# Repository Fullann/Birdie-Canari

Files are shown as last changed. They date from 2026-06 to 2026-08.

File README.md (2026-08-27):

# 🐦 Birdie DIY — Moniteur de qualité d'air open source

> **Reproduction DIY du projet [Birdie® Fresh Air Monitor™](https://birdie.design/fr)** — un indicateur visuel de qualité d'air basé sur le CO2, inspiré du canari des mineurs. Lorsque l'air est bon, l'oiseau se dresse. Lorsque le CO2 dépasse un seuil, il s'abaisse pour vous signaler d'ouvrir les fenêtres.

***

## 📖 À propos du projet

[Birdie®](https://birdie.design/fr) est un produit commercial primé qui utilise un capteur CO2 suisse pour indiquer la qualité de l'air intérieur via une aiguille mobile en forme d'oiseau. Ce dépôt est une **implémentation DIY open source** de ce concept.

La logique de déclenchement est fidèle à l'originale :
- L'oiseau **descend** après **10 minutes consécutives** au-dessus de **1000 ppm** (pas instantanément, pour éviter les faux positifs)
- L'oiseau **remonte** dès que le CO2 repasse sous **950 ppm** (hystérésis de 50 ppm pour éviter les oscillations)

***

## ✨ Fonctionnement

```
CO2 < 950 ppm   → oiseau en haut  (air excellent)
CO2 > 1000 ppm  → oiseau en bas   (aérez !)
  (après 10 min consécutives au-dessus du seuil)
```

Inspiré du canari des mineurs : autrefois, les mineurs emmenaient un canari dans les mines pour détecter les gaz toxiques. Birdie® transpose ce principe à la maison moderne.

***

## 🧰 Matériel nécessaire

| Composant | Référence | Rôle |
|---|---|---|
| Microcontrôleur | XIAO ESP32C6 (Seeed Studio) | Cerveau du projet, Wi-Fi, ESPHome |
| Capteur CO2 | Sensirion SCD41 | CO2, température, humidité (I2C) |
| Servo | SG90 | Indicateur visuel (aiguille oiseau) |
| Chargeur batterie | TP4056 avec protection (DW01A) | Charge LiPo via USB-C/micro-USB |
| Boost converter | MT3608 | Monte la tension 3.7 V → 5 V pour le servo |
| Batterie | LiPo 1S 3.7 V – 3800 mAh | Alimentation principale |
| R1 | 100 kΩ | Pont diviseur batterie (bras haut) |
| R2 | 100 kΩ | Pont diviseur batterie (bras bas) |
| Câbles Dupont | — | Connexions |

***

## 🔌 Schéma d'alimentation

La chaîne d'alimentation fonctionne ainsi :

```mermaid
flowchart TD
    %% No HTML tags in labels, quote if special characters
    USB["🔌 USB (5V)"] --> TP4056["⚡ TP4056 (Chargeur)"]
    TP4056 -- "B+ / B-" --> LIPO["🔋 Batterie LiPo (3.7V)"]
    
    LIPO -- "OUT+ (3.7V)" --> XIAO_BAT["🧠 XIAO ESP32C6 (BAT+)"]
    LIPO -- "OUT+ (3.7V)" --> MT3608["🚀 MT3608 (Boost 5V)"]
    LIPO -- "OUT- (GND)" --> GND["GND (Masse commune)"]
    
    MT3608 -- "OUT+ (5V)" --> XIAO_5V["🧠 XIAO ESP32C6 (5V in)"]
    MT3608 -- "OUT+ (5V)" --> SERVO_VCC["⚙️ Moteur (Servo SG90 - Fil Rouge)"]
    
    style TP4056 fill:#8e44ad,stroke:#9b59b6,stroke-width:2px,color:#fff
    style LIPO fill:#27ae60,stroke:#2ecc71,stroke-width:2px,color:#fff
    style MT3608 fill:#f39c12,stroke:#f1c40f,stroke-width:2px,color:#fff
    style XIAO_BAT fill:#2980b9,stroke:#3498db,stroke-width:2px,color:#fff
    style XIAO_5V fill:#2980b9,stroke:#3498db,stroke-width:2px,color:#fff
    style SERVO_VCC fill:#c0392b,stroke:#e74c3c,stroke-width:2px,color:#fff
```

> ⚠️ **Régler le MT3608 en premier** : avant de connecter quoi que ce soit, ajuster le trimmer du MT3608 à **5.0 V** avec un multimètre. Ne jamais dépasser 5.5 V sur le XIAO ou le SG90.

***

## 🔧 Câblage complet

### Tableau récapitulatif

| Signal | GPIO XIAO | Broche XIAO | Connecté à |
|---|---|---|---|
| I2C SDA | GPIO22 | D4 | SCD41 SDA |
| I2C SCL | GPIO23 | D5 | SCD41 SCL |
| Servo signal | GPIO2 | D2 | SG90 fil orange/jaune |
| ADC batterie | GPIO0 | A0 | Point milieu R1/R2 |
| Alimentation | — | 5V | MT3608 OUT+ et SG90 rouge |
| Alimentation | — | GND | Masse commune |
| SCD41 VCC | — | 3V3 | SCD41 VCC |

### Schéma de câblage

```mermaid
flowchart LR
    subgraph ALIM ["⚡ Alimentation"]
        TP["TP4056"]
        LIPO["Batterie 3.7V"]
        BOOST["MT3608 (5V)"]
    end

    subgraph XIAO ["🧠 Microcontrôleur XIAO ESP32C6"]
        P_5V["Broche 5V"]
        P_3V3["Broche 3.3V"]
        P_GND["GND"]
        P_D4["GPIO22 (D4)"]
        P_D5["GPIO23 (D5)"]
        P_D2["GPIO2 (D2)"]
        P_A0["GPIO0 (A0)"]
    end

    subgraph SENSOR ["👁️ Capteur CO2 (SCD41)"]
        SCD_VCC["VCC"]
        SCD_GND["GND"]
        SCD_SDA["SDA"]
        SCD_SCL["SCL"]
    end

    subgraph MOTOR ["⚙️ Moteur (Servo SG90)"]
        SRV_VCC["VCC (Rouge)"]
        SRV_GND["GND (Marron/Noir)"]
        SRV_SIG["Signal (Orange/Jaune)"]
    end

    %% Power routing
    BOOST -- "5V" --> P_5V
    BOOST -- "5V" --> SRV_VCC
    P_3V3 -- "3.3V" --> SCD_VCC
    
    %% GND routing
    P_GND --- SCD_GND
    P_GND --- SRV_GND
    LIPO -- "GND" --- P_GND
    
    %% Data routing
    P_D4 -- "I2C SDA" --> SCD_SDA
    P_D5 -- "I2C SCL" --> SCD_SCL
    P_D2 -- "PWM" --> SRV_SIG
    
    %% Battery reading (Pont diviseur)
    LIPO -- "Pont Diviseur" --> P_A0
    
    style XIAO fill:#2c3e50,stroke:#34495e,stroke-width:2px,color:#fff
    style SENSOR fill:#27ae60,stroke:#2ecc71,stroke-width:2px,color:#fff
    style MOTOR fill:#c0392b,stroke:#e74c3c,stroke-width:2px,color:#fff
    style ALIM fill:#f39c12,stroke:#f1c40f,stroke-width:2px,color:#fff
```
> **Note :** La masse (GND) doit être commune à tous les composants.

### Pont diviseur — mesure batterie

```mermaid
flowchart TD
    BAT["🔋 BAT+ (3.7V - 4.2V)"] --> R1["Résistance R1 (100 kΩ)"]
    R1 --> NODE(("Point milieu"))
    NODE --> R2["Résistance R2 (100 kΩ)"]
    R2 --> GND["GND (Masse)"]
    
    NODE -. "Lecture de la tension" .-> XIAO_A0["🧠 XIAO GPIO0 (A0)"]
```

| Tension batterie | Tension lue sur A0 |
|---|---|
| 4.2 V (pleine) | ~2.1 V |
| 3.7 V (mi-charge) | ~1.85 V |
| 3.2 V (vide) | ~1.6 V |

***

## ⚡ Versions du firmware ESPHome

Deux versions du firmware sont disponibles dans `esphome/` :

### v1 — Position proportionnelle au CO2

La v1 (`v1.yaml`) mappe **linéairement** la position du servo sur la concentration de CO2 :
- Sous 700 ppm → oiseau tout en haut
- Au-dessus de 1400 ppm → oiseau tout en bas
- Entre 700 et 1400 ppm → position intermédiaire proportionnelle

Le deep sleep réveille l'ESP toutes les **5 minutes** pour prendre une mesure.

> **Avantage :** comportement progressif et intuitif, on voit l'oiseau bouger graduellement.  
> **Inconvénient :** ne reproduit pas la logique exacte du Birdie® original, et consomme plus (réveil fréquent, mesure toutes les 15s).

### v2 — Logique fidèle au Birdie® original ✅ (recommandée)

La v2 (`v2.yaml`) reproduit exactement le comportement du produit commercial :
- L'oiseau est en **position haute** ou **basse**, jamais intermédiaire
- Il descend uniquement après **10 minutes consécutives** au-dessus de 1000 ppm
- Il remonte uniquement si le CO2 passe sous **950 ppm** (hystérésis)
- Un compteur global persistant (`minutes_above_threshold`) survit aux cycles de deep sleep grâce à `restore_value: true`
- Le deep sleep réveille l'ESP toutes les **minutes** pour tenir le compteur à jour, avec endormissement long la nuit (22h–7h)

> **Avantage :** comportement identique au Birdie® original, robuste aux faux positifs.  
> **Inconvénient :** légèrement plus complexe à lire, et l'autonomie dépend directement de la durée du deep sleep.

### Comparatif v1 / v2

| Aspect | v1 | v2 |
|---|---|---|
| Position du servo | Proportionnelle (continu) | Tout-ou-rien (haut/bas) |
| Logique de seuil | Instantanée (CO2 direct) | 10 min consécutives > 1000 ppm |
| Hystérésis | Non | Oui (950 ppm à la remontée) |
| Fidélité au Birdie® | Partielle | Exacte ✅ |
| Intervalle de réveil | 5 min | 1 min (actif) / nuit longue |
| Deep sleep nocturne | Oui (22h–7h) | Oui (22h–7h) |
| Compteur persistant | Non | Oui (`restore_value`) |
| Complexité du code | Simple | Modérée |

> 💡 **Recommandation** : utiliser la v2 pour un comportement fidèle à l'original. Utiliser la v1 si vous préférez un indicateur visuel graduel ou souhaitez expérimenter.

***

## 🚀 Comment flasher le code sur le XIAO ESP32C6

Le code de ce projet utilise **ESPHome**. Voici les étapes simples pour l'installer sur votre carte XIAO :

### Méthode 1 : Via ESPHome Web (La plus simple, sans installation)
1. Branchez votre XIAO ESP32C6 à votre ordinateur via un câble USB-C (assurez-vous qu'il permet le transfert de données).
2. Ouvrez le navigateur **Google Chrome** ou **Microsoft Edge** et allez sur [ESPHome Web](https://web.esphome.io/).
3. Cliquez sur **Connect** et sélectionnez le port série de votre XIAO dans la fenêtre qui s'ouvre.
4. Cliquez sur **Install** puis choisissez le fichier de configuration de ce dépôt (ex: `esphome/v2.yaml`).
5. Renseignez vos identifiants Wi-Fi lorsque cela vous est demandé.
6. Attendez la fin de la compilation et du flashage. Votre oiseau est prêt !

### Méthode 2 : Via Home Assistant (Si vous l'utilisez déjà)
1. Ouvrez Home Assistant et allez dans le module complémentaire **ESPHome**.
2. Créez un nouvel appareil (bouton **New Device**).
3. Nommez-le (ex: `birdie-diy`) et choisissez la plateforme **ESP32-C6**.
4. Copiez le contenu de `esphome/v2.yaml` (ou modifiez-le selon vos besoins) et collez-le dans l'éditeur de configuration du nouvel appareil.
5. Branchez le XIAO à la machine hébergeant Home Assistant, ou utilisez la méthode *Plug into this computer* pour flasher via le navigateur.
6. Cliquez sur **Install** et patientez pendant la création du firmware.

***

## 🏠 Home Assistant — Conserver la dernière valeur

Quand l'ESP est en deep sleep, les entités passent à `unavailable`. Ces **template sensors** conservent la dernière valeur connue et évitent les trous dans les graphiques.

***

## 🔒 Déploiement Docker — ESPHome Dashboard

Pour héberger ESPHome dans Docker derrière un reverse proxy (Traefik, NGINX, etc.) :

```yaml
services:
  esphome:
    container_name: esphome
    image: ghcr.io/esphome/esphome:latest
    environment:
      - USERNAME=admin
      - PASSWORD=motdepassefort        # ⚠️ À changer absolument
    volumes:
      - /opt/docker/esphome:/config
      - /etc/localtime:/etc/localtime:ro
    restart: unless-stopped
networks:
  default:
    name: proxy
    external: true
```

> ⚠️ **Sécurité** : penser aussi à changer le mot de passe du fallback AP (`BirdieDIYFallback`) dans les fichiers YAML ESPHome avant de flasher. La valeur par défaut `12345678` est volontairement simpliste pour les tests.

***

## 📊 Entités Home Assistant disponibles

| Entité | Type | Unité |
|---|---|---|
| `sensor.qualite_air_xiao_co2` | CO2 temps réel | ppm |
| `sensor.qualite_air_xiao_temperature` | Température temps réel | °C |
| `sensor.qualite_air_xiao_humidite` | Humidité temps réel | % |
| `sensor.co2_derniere_valeur` | CO2 (dernière valeur connue) | ppm |
| `sensor.temperature_derniere_valeur` | Température (dernière valeur connue) | °C |
| `sensor.humidite_derniere_valeur` | Humidité (dernière valeur connue) | % |
| `sensor.qualite_air_xiao_batterie_tension` | Tension batterie *(optionnel, nécessite R1/R2)* | V |
| `sensor.qualite_air_xiao_batterie_pourcentage` | % batterie *(optionnel, nécessite R1/R2)* | % |
| `sensor.qualite_air_xiao_etat_birdie` | État textuel (v2 uniquement) | — |

***

## ⏱️ Autonomie estimée

| Composant | Consommation estimée |
|---|---|
| XIAO ESP32C6 actif + Wi-Fi | ~30 mA |
| SCD41 mesure périodique | ~15 mA |
| SG90 pendant mouvement | ~10–20 mA |
| MT3608 (actif) | ~2–5 mA quiescent |
| **Total en fonctionnement** | ~55–70 mA |
| Deep sleep (nuit) | < 1 mA |
| **Autonomie estimée (batterie 3800 mAh)** | **~2 à 3 jours** |

**Pour améliorer l'autonomie :**
- Augmenter l'intervalle de réveil (15 min au lieu de 5 min en v1, ou plus de 1 min en v2 si les mesures de nuit ne sont pas nécessaires)
- Désactiver le MT3608 la nuit avec un transistor (économise ~2–5 mA en continu)
- Utiliser une batterie LiPo plus grande (6000–10000 mAh)
- Désactiver l'API ESPHome si Home Assistant n'est pas utilisé en permanence

***

## 🖨️ Pièces imprimées en 3D

Les fichiers STL/3MF sont dans le dossier [`/parts/`](./parts/).

| Fichier | Description |
|---|---|
| `parts/boitier_principal.stl` | Corps principal du Birdie DIY |
| `parts/support_mural.stl` | Support pour montage mural |
| `parts/oiseau_aiguille.stl` | Aiguille en forme d'oiseau fixée sur le servo |
| `parts/couvercle.stl` | Couvercle arrière du boîtier |

> Paramètres d'impression conseillés : PLA, 0.2 mm de couche, 20% de remplissage, supports activés pour le boîtier.

***

## 📁 Structure du dépôt

```
birdie-diy/
├── README.md                        ← Ce fichier
├── esphome/
│   ├── v1.yaml                      ← Firmware v1 (position proportionnelle)
│   └── v2.yaml                      ← Firmware v2 (logique Birdie® exacte, recommandée)
├── homeassistant/
│   └── templates.yaml               ← Template sensors HA
├── docker/
│   └── docker-compose.yml           ← Config Docker ESPHome
└── parts/
    ├── boitier_principal.stl
    ├── support_mural.stl
    ├── oiseau_aiguille.stl
    └── couvercle.stl
```

***

## 🆚 Birdie DIY vs Birdie® original

| Aspect | Birdie® original | Birdie DIY |
|---|---|---|
| **Prix** | ~149 € | ~15–25 € (composants) |
| **Capteur CO2** | Sensirion (suisse, non communiqué) | Sensirion SCD41 (même fabricant) |
| **Connectivité** | Bluetooth uniquement | Wi-Fi + Home Assistant |
| **Application** | App Birdie® propriétaire | Home Assistant (open source) |
| **Seuil descente** | > 1000 ppm pendant > 10 min | Identique ✅ (v2) |
| **Seuil remontée** | < 950 ppm (hystérésis) | Identique ✅ (v2) |
| **Mouvement oiseau** | Mécanique breveté, silencieux | Servo SG90 (léger bruit) |
| **Alimentation** | Pile AAA ou secteur | LiPo rechargeable via USB-C |
| **Design boîtier** | Design danois primé | Impression 3D DIY |
| **Personnalisation** | Aucune | Code open source modifiable |
| **Notifications** | Via app Birdie® | Via Home Assistant (mobile, email…) |
| **Historique données** | Limité | Complet via Home Assistant |
| **Autonomie** | ~6 mois (pile AAA) | ~2–3 jours (optimisable) |

La principale différence est la **connectivité** : Birdie® original fonctionne en Bluetooth avec une application propriétaire, tandis que cette version DIY utilise le Wi-Fi et s'intègre à Home Assistant — ce qui ouvre l'historique des mesures, les automatisations et les notifications, des fonctionnalités absentes du produit original.

***

## 📝 Licence

Ce projet est open source sous licence **MIT**.  
Il n'est pas affilié à Birdie® ou Birdie Design ApS.  
Pour le produit original : [birdie.design](https://birdie.design/fr)

***

## 🙏 Crédits

- Concept original : [Birdie® Fresh Air Monitor™](https://birdie.design/fr) — Birdie Design ApS (Danemark)
- Capteur CO2 : [Sensirion SCD41](https://sensirion.com/products/catalog/SCD41) (Suisse)
- Firmware : [ESPHome](https://esphome.io)
- Home Assistant : [home-assistant.io](https://www.home-assistant.io)

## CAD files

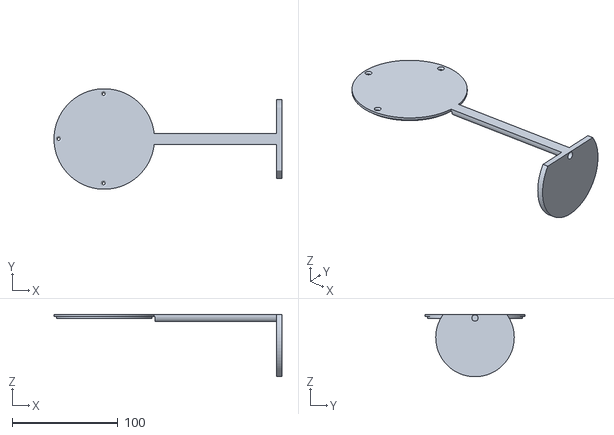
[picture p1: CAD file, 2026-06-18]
parts/arrière_birdie.stl
215.5 x 95.0 x 59.0

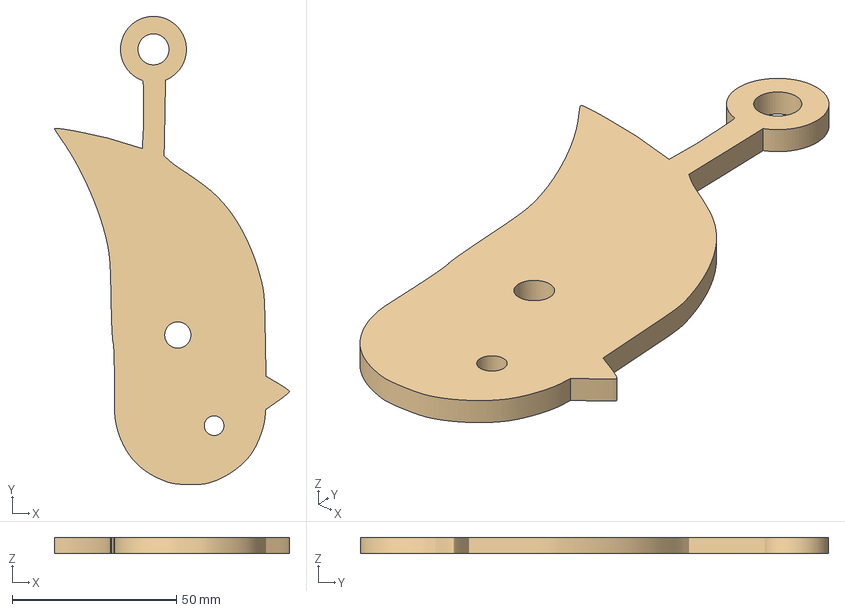
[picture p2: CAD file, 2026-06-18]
parts/bird/corp.3mf
71.6 x 142.7 x 5.00 mm

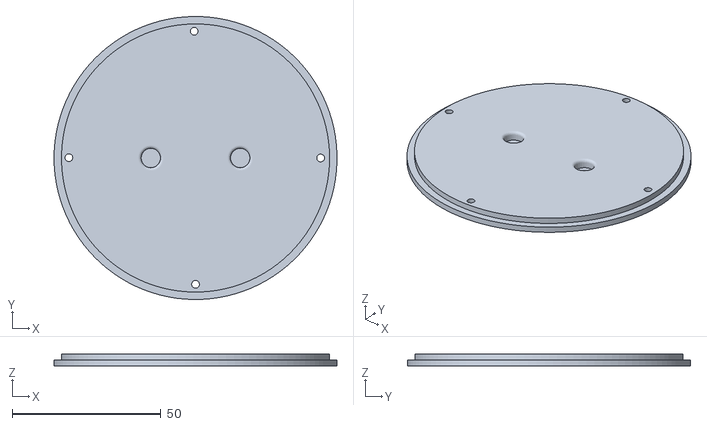
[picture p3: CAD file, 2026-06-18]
parts/box/backBox.stl
95.0 x 95.0 x 4.00

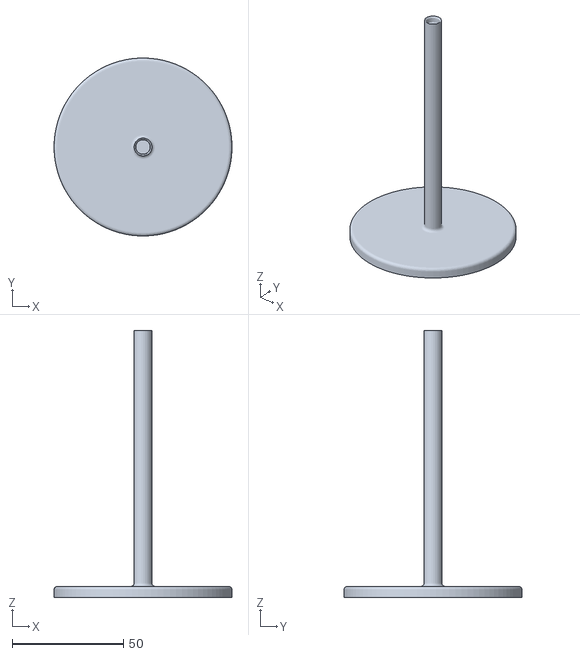
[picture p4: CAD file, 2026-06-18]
parts/support/pied.stl
80.0 x 80.0 x 120.0

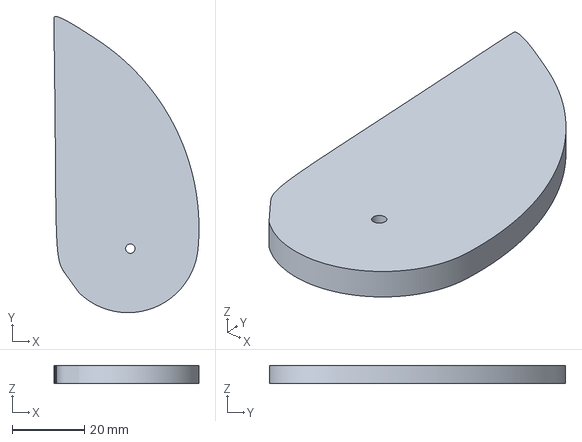
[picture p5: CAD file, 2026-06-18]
parts/bird/aile1.3mf
40.2 x 82.1 x 5.00 mm

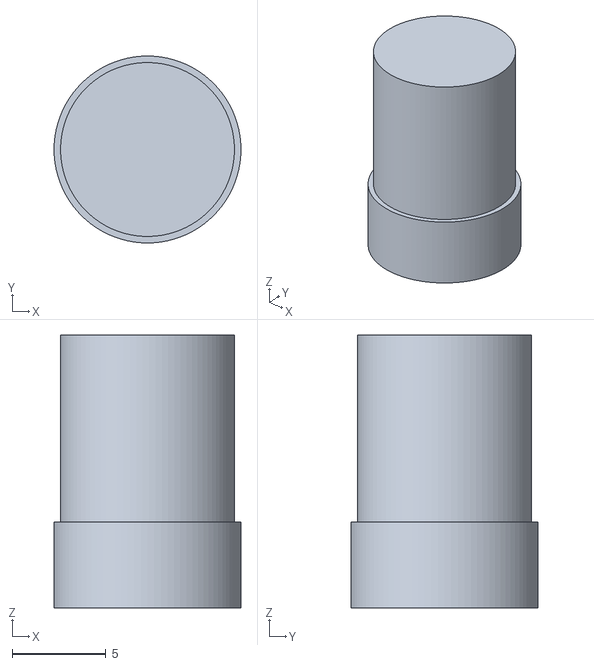
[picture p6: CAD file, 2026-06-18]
parts/box/axe.stl
10.0 x 10.0 x 14.6

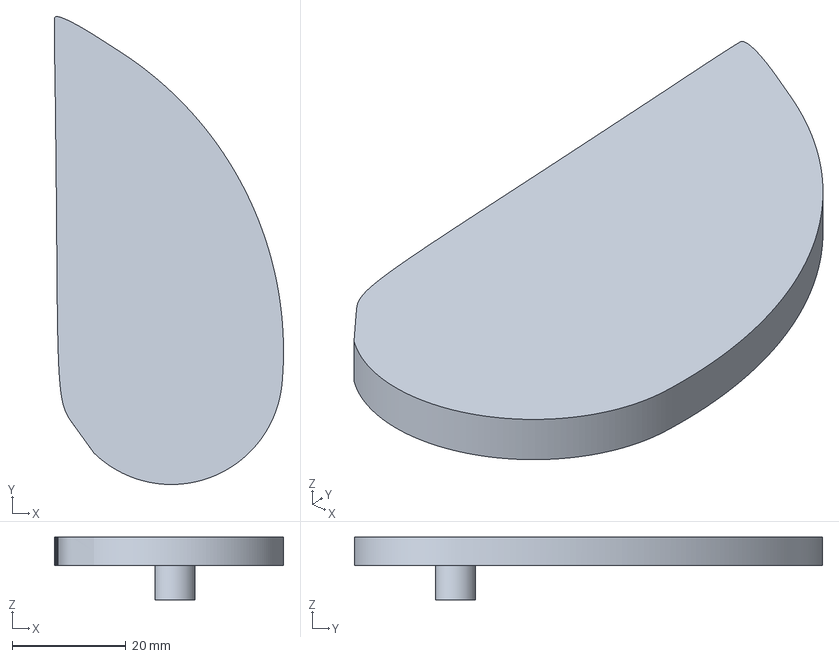
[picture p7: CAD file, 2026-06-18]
parts/bird/aile2.3mf
40.2 x 82.1 x 11.0 mm

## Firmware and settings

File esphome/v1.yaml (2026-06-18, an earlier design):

esphome:
  name: qualite-air-xiao
  friendly_name: Birdie DIY
  on_boot:
    priority: -100
    then:
      - wait_until:
          condition:
            time.has_time:
      - delay: 20s
      - script.execute: update_servo
      - delay: 2s
      - script.execute: manage_sleep

esp32:
  board: seeed_xiao_esp32c6
  framework:
    type: esp-idf

logger:

api:

ota:
  platform: esphome

wifi:
  ssid: "TON_WIFI"
  password: "TON_MOT_DE_PASSE"
  fast_connect: true 
  ap:
    ssid: "BirdieDIYFallback"
    password: "12345678"

captive_portal:

time:
  - platform: homeassistant
    id: ha_time

i2c:
  sda: GPIO22
  scl: GPIO23
  scan: true

sensor:
  - platform: scd4x
    co2:
      name: "CO2"
      id: co2_sensor
    temperature:
      name: "Temperature"
    humidity:
      name: "Humidite"
    address: 0x62
    update_interval: 15s

  # ── Batterie (décommenter quand R1/R2 câblés) ──────────────────────────
  # - platform: adc
  #   pin: GPIO0
  #   name: "Batterie Tension"
  #   id: battery_adc
  #   update_interval: never
  #   attenuation: auto
  #   filters:
  #     - multiply: 2.0
  #
  # - platform: copy
  #   source_id: battery_adc
  #   name: "Batterie Pourcentage"
  #   unit_of_measurement: "%"
  #   device_class: battery
  #   state_class: measurement
  #   filters:
  #     - lambda: |-
  #         float v = x;
  #         if (v >= 4.2) return 100;
  #         if (v <= 3.2) return 0;
  #         return (v - 3.2) * 100.0 / (4.2 - 3.2);
  # ──────────────────────────────────────────────────────────────────────

output:
  - platform: ledc
    pin: GPIO2
    id: servo_output
    frequency: 50 Hz

servo:
  - id: air_servo
    output: servo_output
    transition_length: 2s
    auto_detach_time: 1s

deep_sleep:
  id: deep_sleep_control

script:
  - id: update_servo
    then:
      - if:
          condition:
            lambda: 'return id(co2_sensor).has_state();'
          then:
            - servo.write:
                id: air_servo
                level: !lambda |-
                  float co2 = id(co2_sensor).state;
                  if (co2 <= 700.0f)  return  1.0f;
                  if (co2 >= 1400.0f) return -1.0f;
                  float ratio = (co2 - 700.0f) / 700.0f;
                  return 1.0f - (ratio * 2.0f);

  - id: manage_sleep
    then:
      - lambda: |-
          auto now = id(ha_time).now();
          if (!now.is_valid()) {
            id(deep_sleep_control).set_sleep_duration(300000ULL);
            id(deep_sleep_control).begin_sleep(true);
            return;
          }
          int now_sec = now.hour * 3600 + now.minute * 60 + now.second;
          const int active_start = 7  * 3600;
          const int sleep_start  = 22 * 3600;
          if (now_sec >= sleep_start || now_sec < active_start) {
            int target_sec = active_start;
            if (now_sec >= sleep_start) target_sec += 24 * 3600;
            int sleep_seconds = target_sec - now_sec;
            id(deep_sleep_control).set_sleep_duration((uint64_t)sleep_seconds * 1000ULL);
          } else {
            id(deep_sleep_control).set_sleep_duration(5ULL * 60ULL * 1000ULL);
          }
      - deep_sleep.enter: deep_sleep_control

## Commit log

2026-06-18 add v1 of the project
    [aile1.3mf, aile2.3mf, arrière_birdie.stl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]
2026-09-22 feat: refonte complète des firmwares, ajout BTHome BLE, Zigbee 3.0, buzzer et mise à jour documentation
    - Nouveaux firmwares Arduino C++ :
    * birdie_standalone_v2.ino : logique v2 (10 min conséc.), alerte batterie servo, coupure sécurité, FRC 400 ppm, buzzer passif sur D3 (GPIO21).
    * birdie_bthome.ino : diffusion BLE BTHome V2 basse consommation, auto-découverte Home Assistant, buzzer et autonomie 12-18 mois.
    * birdie_zigbee.ino : end device Zigbee 3.0 natif compatible ZHA et Zigbee2MQTT.
    * birdie_standalone.ino : version autonome ultra-basse consommation (cycle v1).
    - ESPHome :
    * Intégration du monitoring batterie ADC sur GPIO0 (v1.yaml, v2.yaml) avec courbe de décharge LiP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
2026-10-25 feat: ajout photo de présentation, configuration PlatformIO et fiabilisation Zigbee/BTHome
    - docs: ajout photo de présentation du Birdie DIY et intégration dans le README
    - build: ajout du platformio.ini pour compilation et flash direct sous VS Code
    - fix(zigbee): migration Zigbee.h officiel (ESP32 Core 3.x), partition zigbee.csv, sécurité moteur (angles 10°-170°, impulsion 800ms avec detach)
    - fix(bthome): correction de compatibilité String avec advertData.setServiceData
    - docs: mise à jour complète du README (flash PlatformIO, séquence bootloader, câblage TP4056/MT3608)
    - chore: mise à jour du .gitignore (.pio, .vscode, .cache, .DS_Store)
2026-10-25 docs: ajout des photos de montage intérieur et de la plaque PCB au matériel
    - docs: ajout de birdie_interior_top.jpg et birdie_interior_angle.jpg dans docs/images/
    - docs(README): ajout de la section 'Aperçu du montage réel et intégration interne' illustrant l'insertion du PCB vertical sur glissières, de la batterie 18650 et des composants
    - docs(BOM): ajout de la plaque de prototypage (PCB perfboard) et précision de la batterie Li-ion 18650 (3800 mAh)
2026-10-26 fix(firmware): stabilite Zigbee, gestion batterie, protection servo et securisation SCD41
    - Zigbee : elimination des chutes a 0 (mesure physique avant demarrage radio et valeurs par defaut)
    - Zigbee : ajout du rapport batterie manquant (reportBatteryPercentage)
    - Zigbee : Smart Eco Mode (veille 5 min air sain, 60s en alerte, 2 min oiseau en bas)
    - Zigbee : ajout du mode secteur permanent (PERMANENT_POWERED)
    - Servomoteur : allongement du temps de maintien a 2.5s et extension plage PWM (500-2500us)
    - Servomoteur : ajout routine de test de course au demarrage et option SERVO_INVERT
    - Firmwares (BTHome, Standalone v1/v2) : fiabilisation SCD41 (controle d'erreur de lecture) et servo (2.5s)
    - Doc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
